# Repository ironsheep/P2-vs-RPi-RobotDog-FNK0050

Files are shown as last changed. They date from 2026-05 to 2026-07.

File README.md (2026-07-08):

# P2-vs-RPi-RobotDog-FNK0050






One of the things I really enjoy doing is finding robotic platforms with a collection of servos and actuators and sensors that look like they'd be fun to control and might be a good challenge for me to expand my skills in programming the P2. When I find these platforms, I look at how they're set up and how compatible they might be. In this case, this was driven by a Raspberry Pi, so I know the interface is going to be pretty easy to adopt when it comes to taking out the Raspberry Pi and replacing it with a P2.

This project is exactly that: the record of me doing this work of replacing a Pi with a P2 and then building the code around it. I built this so you can follow along and play and even use the code if you wish for experiments on your own. 

-*Stephen*

<p align="center">
  Freenove FNK0050 Robot Dog with the Parallax P2 Edge Module mounted where the Raspberry Pi used to sit
</p>

> *The FNK0050 Robot Dog with the Parallax **P2 Edge Module** mounted in place of the Raspberry Pi — the "P2 EDGE" module and chip are visible on top.*

Porting the **Freenove Robot Dog Kit (FNK0050)** from its stock **Raspberry Pi**
controller to a **Parallax Propeller 2 (P2)**. The P2 — on an Edge Module +
breakout board carried by a custom adapter plate — drops into the spot where the
Pi normally sits and mates to the connection board's 40-pin header.

The goal: drive the same robot hardware (13 servos, IMU, battery ADC, ultrasonic
sensor, buzzer, and WS2812 LEDs) from P2 firmware instead of the Pi's Python stack.

> **This build uses connection board PCB v1.0** — so the WS2812 LED data line is on
> **GPIO18** (the `rpi_ws281x` path), not the SPI0/GPIO10 path used by PCB v2.0.

## Why the P2?

The Freenove design puts almost everything on **I²C** behind driver chips
(PCA9685 servo controller, ADS7830 battery ADC, MPU6050 IMU), so most of the port
is "implement an I²C master on the P2." Only three peripherals use discrete GPIO —
the buzzer, the HC-SR04 ultrasonic sensor, and the WS2812 LED strip — and each maps
naturally onto a P2 smart pin. See the wiring map for the full breakdown.

## Repository layout

| Path | Contents |
|---|---|
| [`DOCs/`](DOCs/) | Project documentation — pin usage, the P2 migration wiring map, mounting hardware CAD, and supporting images/sources. |
| `src/` | P2 firmware (Spin2 / PASM2) — work in progress. |
| `REF/` | Upstream Freenove FNK0050 Raspberry Pi code, kept locally for porting reference. **Git-ignored** — not part of this repo's deliverables. |

## Documentation

Start here when planning or executing the hardware swap:

- **[`DOCs/P2-platform/`](DOCs/P2-platform/)** — the **physical-platform hub**: the
  [build walk-through](DOCs/P2-platform/HARDWARE_SETUP.md) (model/print the adapter plate,
  assemble the P2 board onto it, mount it on the robot), the
  [wiring map](DOCs/P2-platform/P2_MIGRATION_WIRING.md) (power architecture, the 3.3 V
  provenance gotcha, the header→P2 map, and the 3.3 V-vs-5 V hazards — the P2 is **not**
  5 V tolerant), and the adapter-plate **CAD** (DXF + 3MF).
- **[`DOCs/RPI_GPIO_USAGE.md`](DOCs/RPI_GPIO_USAGE.md)** — the stock Pi pin/bus
  usage, reverse-engineered from the Freenove server source (no schematic exists).
  Device inventory, I²C addresses, servo channel map, and which signals ride raw GPIO.

## Hardware reference

- **Kit:** Freenove Robot Dog Kit for Raspberry Pi (FNK0050) —
  https://docs.freenove.com/projects/fnk0050/en/latest/
- **Controller (new):** Parallax Propeller 2 Edge Module + breakout board.
- **Power:** 2× 18650 Li-ion (2S), externally charged; the connection board's
  regulator delivers 5 V to the controller. See the wiring map for details.

## Status

Early-stage. Documentation and mechanical/electrical planning are in place; the P2
firmware in `src/` is under development.

## Possible future directions

These are **candidate** directions for after the current port is fully bench-certified — the
**remaining** items are not committed or in progress, and the current firmware does not depend on any
of them. Each is an *input* that posts into the existing cog-0 command mailboxes, so the motion engine
needs no change. **Full detail — hardware candidates, interfaces, and P2-integration notes — is in
[`DOCs/FUTURE-DIRECTIONS.md`](DOCs/FUTURE-DIRECTIONS.md).**

- **Speech recognition** *(✅ implemented in build 0.3.0)* — spoken commands ("sit", "shake", …) via a
  DFRobot DF2301Q offline recognizer on a 2nd I²C bus, feeding the cog-0 command mailboxes. The dog is
  named **Peabody** (wake phrase "Hello Peabody"); see the release notes and
  [`DOCs/subsystems/VoiceSensor/`](DOCs/subsystems/VoiceSensor/).
- **Pan/tilt head + vision AI camera** *(longer-term)* — replace the tilt-only head with a pan/tilt
  mount + an I²C AI camera that reports what it sees (follow / look-at / find).
- **P2 native audio output** *(longer-term)* — real barks / speech via the P2's smart-pin DAC/PWM,
  beyond today's buzzer.
- **Bluetooth remote commanding** *(longer-term)* — a wireless link (SPI / I²C) driving the same
  mailbox command set; the first real "comms cog 0".

---

## License

MIT License - See [LICENSE](LICENSE) for details. © 2026 Iron Sheep Productions, LLC.

Note: the upstream Freenove reference material under `REF/` (git-ignored) is released
by Freenove under CC BY-NC-SA 3.0 and is not covered by this repository's license.

---

*Part of the Iron Sheep Productions Propeller 2 Projects Collection*

---

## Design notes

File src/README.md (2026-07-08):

# `src/` — P2 Firmware Architecture

P2 (Parallax Propeller 2) firmware that replaces the Raspberry Pi controller in the
**Freenove Robot Dog Kit (FNK0050)**. The P2 must drive the same connection-board
hardware the Pi's Python stack drove. Language is **Spin2 / PASM2**, compiled with
**PNut-ts**.

> **Authoritative hardware facts live in `../DOCs/`**, not here. This README is the
> *static* software map — objects, tiers, files, pins. For how the firmware *runs* at
> runtime (cogs, cooperative tasks, the frontend↔backend mailbox protocol), see the
> companion **`../DOCs/P2_FIRMWARE_THEORY_OF_OPS.md`**. For pin/rail facts and their
> confidence levels, see `../DOCs/P2-platform/P2_MIGRATION_WIRING.md` (the swap) and
> `../DOCs/RPI_GPIO_USAGE.md` (the stock Pi usage). Where this README repeats a pin, it is
> for orientation — the wiring doc wins.
>
> **This build targets connection board PCB v1.0** (WS2812 LED data on the discrete data
> line, not the v2.0 SPI path).

---

## 1. Layered object model

Drivers and behaviors stack in **four tiers**. Tiers 1–3 are the per-device driver shape
already established by the seed `isp_i2c_pca9685*` objects;
Tier 4 is the behavioral/coordination layer that composes devices into a robot.

| Tier | Role | Speaks in… | Examples |
|---|---|---|---|
| **1 — transport** | Raw hardware access; one bus / one signal. Knows no device. | bytes, ACK/NAK, pin transitions | `isp_i2c_singleton`, `isp_ws2812.streamBuffer()` |
| **2 — chip** | Register-level access to one device. | register addresses, raw counts | `isp_i2c_pca9685`, `isp_i2c_ads7830` |
| **3 — semantics** | The *user's* mental model of one part. | degrees, volts, named colors | `isp_i2c_pca9685_servo`, `isp_battery_monitor`, `isp_leg`, `isp_head`, `isp_led_ring` |
| **4 — coordination** | Composes many parts into whole-robot behavior. | gaits, poses, commands | `isp_dog_motion`, `isp_io_controller`, `isp_led_engine` |

Three structural notes:

- **The tier boundary is about *vocabulary*, not `PUB`/`PRI`.** Plenty of Tier-2 register
  pokes are `PUB` on purpose (handy for bring-up/probing). What makes a method "Tier-3" is
  that it talks degrees/volts/colors, never register counts.
- **Tiers can split across files *or* live in one file.** I²C devices get a Tier-1 bus
  singleton shared by all chips, so their tiers are separate objects. The WS2812 has no
  shared bus, so its transport+framing live inside one object — like the serial singleton
  keeps its bit-level smart-pin code and its `dec`/`hex`/`fstr` API in one file.
- **Tiers are a static call hierarchy; cogs are a separate runtime partition.** Which cog
  runs which tier — and why all the I²C-bound objects must run in *one* cog — is the
  Theory of Operations' job, not this map's.

---

## 2. Object inventory & dependency tree

```
robot_dog_top        (T4 top: cog0 voice dispatch loop; cogspins the two service cogs)
  ├─ isp_io_controller       (cog1: discrete-pin + voice-bus owner, mailbox B)  → expanded below
  ├─ isp_dog_motion          (cog2: I²C bus-1 owner, mailbox A)                  → expanded below
  ├─ isp_voice_command_names (maps DF2301Q CMDID → phrase text for the dispatch log)
  └─ isp_version             (firmware version constants — single source of truth)

isp_dog_motion            (T4: 4 legs + head + IMU + battery; smooth-motion engine, gait catalog, poses, gestures, leveling)
  ├─ isp_leg  ×4         (T3: one leg; moveToXYZ via shared IK, side-mirror, per-leg calibration)
  │   └─ isp_i2c_pca9685_servo  ×3   (T3 servo, seed)
  ├─ isp_head            (T3: pan/center/sweep, PCA9685 ch 15)
  │   └─ isp_i2c_pca9685_servo
  ├─ isp_imu             (T3: attitude — accel g / gyro °/s)        ─┐
  │   └─ isp_i2c_mpu6050 (T2: MPU6050 registers)                    │
  ├─ isp_battery_monitor (T3: pack volts, low-batt cutoff, median)  │
  │   └─ isp_i2c_ads7830 (T2: ADS7830 counts / pin millivolts)      ├─ isp_i2c_pca9685 (T2)
  └─ isp_calibration     (per-joint servo trims + stance leveling)  │     │
                                                                    │     └─ isp_i2c_singleton (T1: I²C master, bus 1)
isp_io_controller        (T4 IO cog: non-blocking LED + buzzer + ranging + voice service loop)
  ├─ isp_led_engine      (T4: SOLE owner of the ring; sustained base modes + single-shot cues)
  │   └─ isp_led_ring    (T3: display modes; owns LED count)
  │       └─ isp_ws2812  (T1+T2: WS2812 transport + pixel buffer)
  ├─ isp_buzzer          (T2+T3: buzzer, smart pin — no I²C)
  ├─ isp_hcsr04          (T2+T3: ultrasonic, smart pin — no I²C)
  └─ isp_voice_recognizer (T3: DF2301Q @ 0x64 on I²C bus 2, P18/P16; clock-stretch)
      └─ isp_i2c         (T1: VAR/instance I²C master, bus 2)

(every object) ── DEBUG() built-in (debug output over the 2 Mbaud programming UART)
```

All objects below **compile clean** with PNut-ts v1.55 (`pnut-ts -q`). Items marked
**⚠ verify** contain math/timing inferred from the Freenove code or datasheets that must be
validated on hardware (outputs are clamped, so they are safe to run during bring-up).

| File | Tier | Device / role | Notes |
|---|---|---|---|
| `isp_i2c_singleton.spin2` | 1 | I²C bus master | **seed**; shared by all I²C chips. `setup/present/write/read/wr_block/rd_block/stop`. ACK=0, NAK=1 |
| `isp_i2c_pca9685.spin2` | 2 | PCA9685 @ `0x40` | **seed**; 16-ch PWM register driver |
| `isp_i2c_pca9685_servo.spin2` | 3 | servo | **seed**; degrees/µSec, limits, slew ramp tables |
| `isp_i2c_ads7830.spin2` | 2 | ADS7830 @ `0x48` | `readChannelRaw` / `readChannelMillivolts` (divider-agnostic). VREF 5.0 V (consistent with the metered ÷3 battery) |
| `isp_battery_monitor.spin2` | 3 | battery | 9-sample median, **÷3 divider** undo (METERED 2026-06-01), `isLowBattery` (<6.4 V) |
| `isp_ws2812.spin2` | 1·2 | WS2812 strip (7 px) | inline-PASM, CT-paced fixed-cell + GRB buffer (dumb strip). Timing per jm_rgbx_pixel; confirm WS2812 vs B variant |
| `isp_led_ring.spin2` | 3 | LED display modes | off/solid/wipe/chase/rainbow/rainbow-cycle/**rainbow-breathe**; `update()` steps one frame |
| `isp_led_engine.spin2` | 4 | LED engine (sole ring owner) | command-driven: sustained **base** modes + single-shot **cue** overlays (`blink`, latest-wins, revert to base); per-mode pacing (30 ms smooth / 130 ms marching); `service()` stepped by the IO cog. Fixed the earlier multi-writer race |
| `isp_io_controller.spin2` | 4 | discrete-pin + voice-bus IO cog | non-blocking service loop: LED engine + smart-pin ranging + auto-off buzzer + **DF2301Q voice poll (bus 2)**; mailbox B (`postCommand`, `getDistanceMm`/`getPingSeq`/`isLedBusy`, `getVoiceCmdId`/`getVoiceSeq`/`voicePresent`); `start` (voice-off) / `startWithVoice` |
| `isp_i2c_mpu6050.spin2` | 2 | MPU6050 @ `0x68` | wake + ±2g/±250°/s; burst-read accel/gyro raw |
| `isp_imu.spin2` | 3 | attitude | accel milli-g, gyro milli-°/s, `calibrateGyro` (settle + paced + motion-reject → SUCCESS/E_NOT_STILL), `tiltDegrees` (CORDIC). Mahony fusion = TODO |
| `isp_hcsr04.spin2` | 2·3 | HC-SR04 ultrasonic | polled `readDistanceMm`/`Cm` **and** non-blocking smart-pin path (`startSmart`/`firePing`/`echoReadyMm`) ⚠ verify integrated |
| `isp_buzzer.spin2` | 2·3 | buzzer | active buzzer `on`/`off`/`beep` (IO cog drives non-blocking via auto-off tick) |
| `isp_leg.spin2` | 3 | one leg (3 servos) | `init(side, ending)`, `setJointAngles`, `moveToXYZ` (CORDIC IK ⚠ verify) |
| `isp_head.spin2` | 3 | head pan (ch 15) | `panTo`/`center`/`sweep` |
| `isp_calibration.spin2` | 3 | per-robot trims | per-joint servo trims (metered) + head trim + **static stance leveling** (`stanceTrimY`) |
| `isp_dog_motion.spin2` | 4 | body coordinator | `{Spin2_v47}` cooperative tasks; mailbox A; smooth-motion engine (50 Hz eased), full gait catalog + speed knob, stand/relax/sit, hello, leveling ⚠ verify |
| `isp_i2c.spin2` | 1 | I²C bus master (VAR/instance) | clock-stretch-honoring instance variant for **bus 2** (voice); mirrors the DAT singleton but stores bus state per-instance |
| `isp_voice_recognizer.spin2` | 3 | DF2301Q @ `0x64` (bus 2) | offline voice recognizer over `isp_i2c`; `getCMDID`/`pollCMDID`, `playByCMDID`, `setVolume`/`setWakeTime`, register-liveness presence probe (defeats parasitic-power false positive) |
| `isp_voice_command_names.spin2` | 3 | CMDID → phrase names | built-in vocabulary tables + `registerCustomTable()` for custom slots 5–21; `cmdName(id)` → text (dispatch log) |
| `isp_version.spin2` | — | firmware version | single source of truth `FW_VERSION_MAJOR/_MINOR/_PATCH` (0.3.0) |
| `robot_dog_top.spin2` | 4 | integrated 3-cog top | `cogspin`s IO (cog1) + backend (cog2); runs the **persistent voice dispatch loop** — maps recognized CMDID→`CMD_*` (`voiceToDogCmd()`) and posts to mailbox A through the motion gate; legacy scripted self-test behind `DEMO_ON_BOOT` ⚠ verify (live voice→motion) |

There is **no shared OBEX driver** for the ADS7830, MPU6050, or HC-SR04 — each is
hand-rolled on the seed I²C singleton (or a smart pin). The **full gait catalog**
(forward/backward, turn L/R, sidestep L/R) and the hello gesture in `isp_dog_motion` are
implemented on the smooth-motion engine (build 0.1.1); on-bench behavioral verification is
pending (the trajectory math is still ⚠ verify).

---

## 3. The leg model (Tier 3 → Tier 4)

The 12 leg-joint PCA9685 channels group into **4 legs of 3 joints** (coxa *a* / femur *b* /
tibia *c*; link lengths l1=23, l2=55, l3=55 mm). A leg is created with its body position —
**`init(side, end)`** — and derives its own channel triple, joint-angle mirror, and gait
role from that identity.

| Leg | Side | End | coxa (a) | femur (b) | tibia (c) |
|-----|---|-----|---|---|---|
| FL | Left | Front | ch 4 | ch 3 | ch 2 |
| BL | Left | Back | ch 7 | ch 6 | ch 5 |
| BR | Right | Back | ch 8 | ch 9 | ch 10 |
| FR | Right | Front | ch 11 | ch 12 | ch 13 |

- **Side** owns the joint-angle **mirror**: Left legs apply `[a, 90−b, c]`; Right legs apply
  `[a, 90+b, 180−c]`. (Left channels count *down*; Right count *up* — the physical mirror.)
- **End** owns the **gait phase** and stance-offset sign. Diagonal phase pairs are {FL,BR}
  and {FR,BL}.
- **IK lives in `isp_leg`** (`moveToXYZ` = shared `coordinateToAngle` + side-mirror + this
  leg's calibration → 3 servo writes). The **body coordinator** (`isp_dog_motion`) generates
  per-leg target coordinates for gaits/poses and calls each leg.
- **Motion timing lives at the body level (the smooth-motion engine).** `isp_dog_motion` owns a
  CT-gated 50 Hz frame loop with body-level foot-target arrays (`cur/tgt/start[]`, leg order
  FL/BL/FR/BR), an ease-in/out smoothstep, per-frame reachability guard, and blend-from-current —
  so all 13 joints share one timebase and start/arrive together (no per-servo slew, no snaps). It
  drives the **full gait catalog** (forward/backward, turn L/R, sidestep L/R; trotting diagonals
  with an `arg0` speed knob). All poses and gaits share one neutral — the **loaded-rear crouch** —
  through a single source of truth, `neutralFootTarget(idx)` / `neutralFootY(idx)`: front feet at
  `NEUTRAL_FRONT_Y_MM=95`, rear folded deeper to `NEUTRAL_REAR_Y_MM=85` and tucked back
  (`NEUTRAL_REAR_X_MM=−12`) for a ~60:40 forward bias. Gaits clamp each foot's lift to its **own**
  per-leg planted floor (`plantFloor`), so the front/rear height split survives walking;
  `STAND_HEIGHT_MM=99` is retained only as the *tall* SIT/BOW/PARADE reference. The neutral folds in
  the **IMU static-leveling** stance trim (`isp_calibration.stanceTrimY`). The behavioral contract is
  specified in
  [`../DOCs/spec/P2-RobotDog-Specifications.md`](../DOCs/spec/P2-RobotDog-Specifications.md); the
  as-built engine is ToOps §6.2.
- **The three cogs are assembled in `robot_dog_top`** — it `cogspin`s `isp_io_controller` (cog 1:
  discrete pins + voice bus, mailbox B) and the backend (cog 2: I²C, mailbox A), and runs the
  **persistent voice dispatch loop** on cog 0 (maps a recognized CMDID → `CMD_*` via `voiceToDogCmd()`
  and posts to mailbox A through the motion gate).

> ✅ The FL/BL/BR/FR ↔ channel assignment is **verified on hardware 2026-06-01** — each commanded
> leg moved the matching physical leg (FL=4/3/2, BL=7/6/5, BR=8/9/10, FR=11/12/13, head=15). The
> joint-angle **side mirror** and the **CORDIC IK** still need validation through motion (the
> calibration step). Note: at center the FL/BR toes sit slightly low → small tibia trim pending.

Head is a single DOF (PCA9685 **ch 15**, center ≈ 90°, ~50–130°). `isp_head` is intentionally
thin — it earns its keep as the mount point for the future head-pan + ultrasonic scan.
Whole-robot gestures (push-ups, the "hello" wave — which actually waves a *leg*) belong to
`isp_dog_motion`, not the head.

---

## 4. P2 pin map (as-built P8–P15)

**As-built adapter map, verified on hardware 2026-05-31** (base P8; offsets LED +0, ECHO +1,
Buzzer +2, TRIG +3, SCL +5, SDA +7). **Authoritative table + rationale:
`../DOCs/P2-platform/P2_MIGRATION_WIRING.md` §3.**

| P2 pin | Robo hdr pin | Signal | Driver object | Transport |
|---|---|---|---|---|
| P8 | 12 | WS2812 LED data | `isp_ws2812` | inline PASM2 |
| P9 | 15 | Ultrasonic ECHO (input) | `isp_hcsr04` | smart pin (pulse in); **~1 kΩ inline series R** |
| P10 | 11 | Buzzer | `isp_buzzer` | smart pin |
| P11 | 13 | Ultrasonic TRIG | `isp_hcsr04` | smart pin (pulse out) |
| P12 | — | *spare* | — | — |
| P13 | 5 | I²C SCL | `isp_i2c_singleton` | I²C (`PU_1K5`) |
| P14 | — | *spare* | — | — |
| P15 | 3 | I²C SDA (bus 1) | `isp_i2c_singleton` | I²C (`PU_1K5`; 6.9 kΩ board pull-down) |
| P16 | — | I²C SDA (**bus 2, voice**) | `isp_voice_recognizer` via `isp_i2c` | I²C (`PU_1K5`) |
| P18 | — | I²C SCL (**bus 2, voice**) | `isp_voice_recognizer` via `isp_i2c` | I²C (`PU_1K5`) |

> **Bus 2 (voice)** — P16/P18 sit **outside** the P8–P15 as-built block (they were unallocated). The
> DF2301Q voice recognizer (`0x64`) wires **direct to the module**, not through the robot header, and is
> owned by the IO cog (cog 1). See wiring §3a.

### Devices behind the I²C bus (P13/P15)

| Device | Addr (7-bit) | Driver | Role |
|---|---|---|---|
| PCA9685 | `0x40` | `isp_i2c_pca9685(_servo)` | 13 servos: ch 2–13 = four legs (3 joints each), ch 15 = head pan; 0–180° → count 102–512 |
| ADS7830 | `0x48` | `isp_i2c_ads7830` → `isp_battery_monitor` | battery ADC ch 0; cutoff < 6.4 V |
| MPU6050 | `0x68` | `isp_i2c_mpu6050` → `isp_imu` | 6-axis IMU for balance/attitude |

> All three I²C devices share **one** physical bus → exactly one cog may drive it. See the
> Theory of Operations for the bus-ownership rule.
>
> Drivers store the address **pre-shifted** (e.g. ADS7830 = `$90` = `0x48 << 1`) and OR in
> `MODE_WRITE` (0) / `MODE_READ` (1), matching the PCA9685 convention.

---

## 5. Runtime overview (→ Theory of Operations)

The static tiers above are partitioned across P2 cogs at runtime, by **resource ownership** —
comms plus two service cogs, one per hardware domain. In brief:

- **Cog 0 — comms / voice dispatch:** owns the command link only; runs the persistent voice dispatch
  loop — reads the IO cog's voice telemetry, maps each CMDID → behavior (`voiceToDogCmd()`), and posts
  intents to both service cogs while reading their telemetry. Never blocks on a peripheral.
- **Cog 1 — discrete-pin + voice IO** (launched first): owns the **non-I²C pins** — WS2812 LED (P8),
  buzzer (P10), ultrasonic (ECHO P9 / TRIG P11) — **and I²C bus 2** (P18/P16) for the DF2301Q voice
  recognizer. One owner per pin (cross-cog pin handoff is costly); runs the LED engine, ranging, beeps,
  and voice polling as non-blocking tasks (smart-pin timing → ~1 % cog load, no jitter); it is the
  ultrasonic distance producer and the recognized-CMDID producer.
- **Cog 2 — backend body-control:** the **sole owner of I²C bus 1** (servos + IMU + battery); runs
  motion and IMU/battery sensing as **Spin2 v47 cooperative tasks** — so the shared bus is never
  touched by two cogs, with no lock.

Each service cog is fed by its own hub mailbox (commands in, telemetry out). The full cog map,
the concurrency model, the mailbox protocol, and the backend state machine are documented in
**`../DOCs/P2_FIRMWARE_THEORY_OF_OPS.md`**.

---

## 6. Electrical gotchas (recap — see wiring doc for the authoritative treatment)

- **The P2 cannot *drive* 5 V, and a *bare* pin must stay ≤ ~3.6 V — but it can safely *read* 5 V
  through a series resistor** (the pin's internal clamp diode to VIO absorbs the overshoot at ≤ 10 mA,
  so R ≥ (Vin − 3.6)/10 mA ≈ 1 kΩ). **HC-SR04 ECHO** carries **undivided 5 V** on header pin 15 (the
  board does *not* divide it, metered 2026-05/06-01), so it reaches **P9 through a ~1 kΩ series R** —
  ranging is verified working. **WS2812** data is 3.3 V out into a 5 V strip (works on this hardware; a
  74AHCT125 level shifter is the robust fix if the first pixel is ever flaky).
- **The 3.3 V rail vanishes with the Pi.** The adapter must put 3.3 V back on header
  pins 1/17 for the board's I²C pull-ups/chips. (#1 gotcha.)
- **Power flows robot → controller**: feed the P2 board 5 V (header pins 2/4); it regulates
  3.3 V on-board.
- **Keep I/O on P0–P57.** P58–P61 = boot flash, P62/P63 = serial/programming.

Constants once flagged `INFERRED` are being retired as hardware confirms them: the battery
divider is now **METERED ÷3** (2026-06-01), not the ÷2 traced from Freenove code; WS2812 bit
timing matches `REF jm_rgbx_pixel` (only the strip variant needs confirming); the **leg↔channel
map is verified** (2026-06-01). Still to validate through motion: the joint side-mirror, the CORDIC
IK, and per-joint servo trim (the calibration step).

---

## 7. Building

Compiled with **PNut-ts** (`pnut-ts`, v1.55.0+ in this container).

```bash
# Compile one object as the top file (pulls in its child objects automatically):
pnut-ts -q src/isp_ws2812.spin2          # → isp_ws2812.bin

# Useful flags:
pnut-ts -l src/isp_i2c_ads7830.spin2     # also emit .lst listing
pnut-ts -d src/<top>.spin2               # compile with DEBUG
```

Each driver is written so it compiles standalone (it is a valid top object even though its
`null()` notes "not a top-level object"). Objects using cooperative tasks must begin with
the **`{Spin2_v47}`** version directive.

### Proving drivers on hardware — `test_*.spin2` harnesses

Each interface has a dedicated **auto-run** top file (`test_led`, `test_i2c_scan`, `test_buzzer`,
`test_ping`, `test_battery`, `test_imu`, `test_servo_center`, `test_servo_wiggle`, plus `test_smoke`)
that brings up **one** driver, runs it
for a bounded time, and emits P2 `DEBUG()` (no serial singleton, no menu, no keystrokes). Each
declares `DEBUG_BAUD = 2_000_000`, is compiled with `-d`, and ends with `DEBUG("TEST_DONE")`:

```bash
pnut-ts -d -q src/test_i2c_scan.spin2                                       # build with DEBUG
pnut-term-ts -r src/test_i2c_scan.bin -b 2000000 --headless \
             --end-marker "TEST_DONE" --timeout 12                          # download-to-RAM, run, capture
```

> **`-b 2000000` is required.** In `--headless` mode `pnut-term-ts` opens the port at 115200 for the
> *download* (fine, ignore it) but does **not** auto-apply the debug baud to the *runtime* read — so
> 2 Mbaud `DEBUG` comes back as garbage unless you pass `-b 2000000`. Logs land in `logs/`.

These were used for the 2026-06-01 bring-up (results: `../DOCs/P2-platform/P2_MIGRATION_WIRING.md` §7). The smooth-motion bench tests
**all run the production 3-cog shape** (both service cogs launched, isolation by what cog 0
commands — never a single-cog shape): **`test_dog_stand.spin2`** (eased poses), **`test_dog_level.spin2`**
(IMU static-leveling measure), and **`test_dog_gaits.spin2`** (full gait catalog + speed) each keep
the IO cog present-but-quiescent (static LED, ranging dormant), while **`robot_dog_top.spin2`**
runs the **persistent voice dispatch loop** by default (the legacy full-concurrency self-test — LED
animation + live ranging + motion + beep at once — is preserved behind `DEMO_ON_BOOT`). They drive
`DOCs/plans/SMOOTH-MOTION-AND-INTEGRATION-TEST-PLAYBOOK.md`. Voice is exercised in isolation by
**`test_voice.spin2`** (do we hear commands over I²C bus 2) and **`test_voice_map.spin2`** (catalog the
trained custom slots 1:1); the LED engine by **`test_led_engine.spin2`** / **`test_led_onoff.spin2`**.
The real frontend comms cog (Wi-Fi/serial command link) is still **TODO** — **voice is today's command
source**.

`.bin` / `.lst` / `.obj` outputs are build artifacts — don't commit them.

---

## 8. Conventions

- **Coding standards (authoritative):** every `.spin2` file MUST follow
  [`../DOCs/policy/SPIN2-AUTHORING-GUIDE.md`](../DOCs/policy/SPIN2-AUTHORING-GUIDE.md) —
  ASCII-only, VSCode/PNUT_TS doc-comment style (`@param`/`@returns`/`@local`), single exit
  point, `quit` (never `return`) from loops, named constants (no magic numbers), descriptive
  names (no single-letter/generic locals), and object constants referenced via the OBJ
  prefix. The guide's checklist is the pre-commit gate.
- **Naming:** `isp_<...>.spin2`, Iron Sheep Productions prefix. If the device is reached over
  **I²C**, put `i2c` in the name (`isp_i2c_ads7830`); smart-pin / single-signal / behavioral
  objects omit it (`isp_ws2812`, `isp_hcsr04`, `isp_leg`, `isp_dog_motion`).
- **Debug:** objects emit diagnostics via the built-in `DEBUG()` (compiled out unless the
  debugger is attached); output lands on the 2 Mbaud programming UART.
- **License:** MIT, © Iron Sheep Productions, LLC (see each file's footer). Upstream
  Freenove `REF/` material is CC BY-NC-SA 3.0 and is **excluded** from this repo.
- **P2 KB / OBEX:** for PASM2/Spin2 questions and reusable objects, use the **p2kb-mcp**
  tools (authoritative) rather than web search.

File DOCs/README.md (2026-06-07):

# DOCs — P2 Robot Dog documentation hub







Documentation for porting the **Freenove Robot Dog Kit (FNK0050)** from its stock Raspberry
Pi controller to a **Parallax Propeller 2**. Start at the top-level [project README](../README.md);
this page indexes everything under `DOCs/` and records how we reference the upstream Freenove
material.

## Top-level documents

| Document | What it is |
|---|---|
| [`RPI_GPIO_USAGE.md`](RPI_GPIO_USAGE.md) | The stock Pi pin/bus usage, reverse-engineered from the Freenove server source — device inventory, I²C addresses, servo channel map. |
| [`P2_FIRMWARE_THEORY_OF_OPS.md`](P2_FIRMWARE_THEORY_OF_OPS.md) | Theory of operation for the P2 firmware — the cog architecture and the basic→advanced motion progression. |
| [`DOG-LIKE-MOTION-STUDY.md`](DOG-LIKE-MOTION-STUDY.md) | Canine-biomechanics findings + the prioritized plan to make the gaits and poses more dog-like. |
| [`FUTURE-DIRECTIONS.md`](FUTURE-DIRECTIONS.md) | Candidate post-certification directions — speech, vision/pan-tilt head, P2 audio, BLE, active IMU balance. |
| [`pin-header.pdf`](pin-header.pdf) | The 40-pin connection-board header pin-out diagram (source in [`sources/`](sources/)). |

## Subfolders

| Folder | Contents |
|---|---|
| [`P2-platform/`](P2-platform/) | The physical swap — build walk-through, the migration wiring map, and the adapter-plate CAD. |
| [`spec/`](spec/) | The authoritative firmware specification. |
| [`policy/`](policy/) | Authoring conventions (the Spin2 guide). |
| [`plans/`](plans/) | Active sprint plan, bench playbook, and punch list (closed plans in `plans/archive/`). |
| [`dbg-display-theory/`](dbg-display-theory/) | How we build the P2 DEBUG-window display panels. |
| [`reference/`](reference/) | User guides for reused helper objects. |
| [`datasheet/`](datasheet/) | Vendor datasheets for the on-board parts (third-party). |
| [`Picture/`](Picture/) | Images referenced by the docs. |
| [`sources/`](sources/) | Editable diagram source files. |

## Upstream / external reference material — Freenove FNK0050

This port is built against Freenove's open-source kit. We reference that material in two
places, and **neither is covered by this project's MIT license**:

- **The Freenove Raspberry Pi Python stack** lives locally in `REF/` as **read-only**
  porting reference. It is **git-ignored** — never committed to this repo — and is the source
  the P2 drivers were reverse-engineered from (see [`RPI_GPIO_USAGE.md`](RPI_GPIO_USAGE.md)).
- **Kit photos** under [`Picture/`](Picture/) (the kit icon and the PCB-version photos) come
  from Freenove.

Freenove's materials are released under the
[Creative Commons Attribution-NonCommercial-ShareAlike 3.0 license](http://creativecommons.org/licenses/by-nc-sa/3.0/),
and the Freenove brand and logo are their property. Their upstream repository:
[Freenove_Robot_Dog_Kit_for_Raspberry_Pi](https://github.com/Freenove/Freenove_Robot_Dog_Kit_for_Raspberry_Pi).

> **This build targets connection-board PCB v1.0** (WS2812 LED data on GPIO18 — the
> `rpi_ws281x` path, not the v2.0 SPI0/GPIO10 path).

<table>
  <tr><th>PCB Version</th><th>Photo</th></tr>
  <tr>
    <td align="center"><b>V1.0</b> <em>(this build)</em></td>
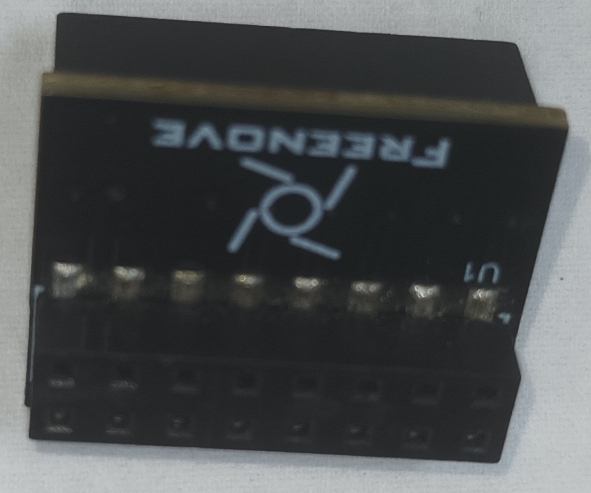
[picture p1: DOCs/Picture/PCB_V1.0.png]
Connection board V1.0
    <td align="center"></td>
  </tr>
  <tr>
    <td align="center">V2.0</td>
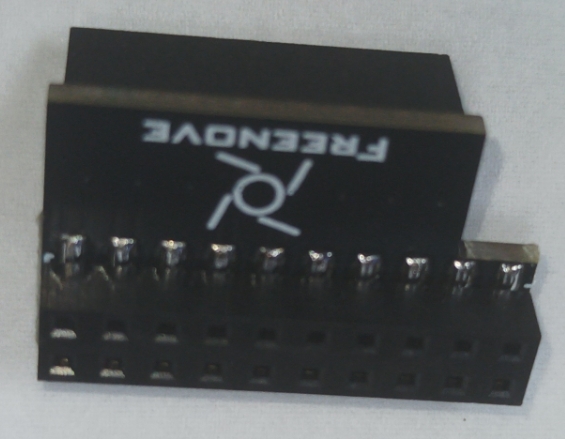
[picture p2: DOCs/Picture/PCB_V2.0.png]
Connection board V2.0
    <td align="center"></td>
  </tr>
</table>

---

## License

The documentation in this `DOCs/` tree is authored by Iron Sheep Productions, LLC and
released under the MIT License — See [LICENSE](../LICENSE) for details. **Exceptions:** the
Freenove-sourced kit images and the third-party vendor datasheets noted above retain their
respective owners' licensing and are **not** covered by MIT.

---

*Part of the Iron Sheep Productions Propeller 2 Projects Collection*

---

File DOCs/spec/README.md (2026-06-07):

# spec — firmware specifications






The authoritative firmware specification for the P2 Robot Dog — the contract the code is
written to. The companion narrative is [`../P2_FIRMWARE_THEORY_OF_OPS.md`](../P2_FIRMWARE_THEORY_OF_OPS.md).

| File | What it covers |
|---|---|
| [`P2-RobotDog-Specifications.md`](P2-RobotDog-Specifications.md) | Full firmware spec — overview, the smooth-motion engine contract, the verified neutral stance, the gait catalog, IMU leveling, and the leg kinematics / servo facts / per-joint clamps / calibration (§8). |

---

## License

MIT License - See [LICENSE](../../LICENSE) for details.

---

*Part of the Iron Sheep Productions Propeller 2 Projects Collection*

---

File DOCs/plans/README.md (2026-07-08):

# plans — sprint plans, playbooks & the punch list






Working planning documents — the **active** sprint plan, the bench-verification playbook
it executes against, and the running punch list. Completed/superseded plans move to
[`archive/`](archive/) so this level always shows what's live.

### Active

| File | What it is |
|---|---|
| [`PUNCH-LIST.md`](PUNCH-LIST.md) | Running list of small open/deferred items (e.g. LED gamma correction). |
| [`VOICE-INTEGRATION-SPRINT-PLAN.md`](VOICE-INTEGRATION-SPRINT-PLAN.md) | The voice-recognition sprint plan. |
| [`VOICE-INTEGRATION-TEST-PLAYBOOK.md`](VOICE-INTEGRATION-TEST-PLAYBOOK.md) | Its bench-verification playbook. |

_The **Voice Integration** sprint shipped in build 0.3.0 (2026-06-11): the 2nd-bus voice recognizer, the
cog-0 dispatch loop, the confirmed **17-word command map** (`voiceToDogCmd()` wired live, plus built-in
aliases), and the command-driven **LED engine** are all **code-complete and bench-confirmed**. Remaining
before closeout/archive: the **live end-to-end voice→motion demo** and the **full LED feedback scheme**.
(The earlier **Dog-Like-Motion-01 Keystone** sprint closed at build 0.2.0 and is in [`archive/`](archive/).)_

> Note: the voice sprint plan/playbook were authored for the **plumbing** phase, when the map seam
> deliberately returned `CMD_NONE`. The CMDID→behavior map has **since been completed** — see
> [`../subsystems/VoiceSensor/VOICE-COMMAND-MAP.md`](../subsystems/VoiceSensor/VOICE-COMMAND-MAP.md) and
> the Theory of Operations §2/§5 for the current behavior.

### Archive

Closed-out plans, kept for history — see [`archive/`](archive/).

---

## License

MIT License - See [LICENSE](../../LICENSE) for details.

---

*Part of the Iron Sheep Productions Propeller 2 Projects Collection*

---

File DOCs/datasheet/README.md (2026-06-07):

# datasheet — vendor datasheets for the on-board parts






Manufacturer datasheets for the silicon on the Robot Dog connection board, kept locally
so the register-level details are at hand while writing the P2 drivers. Device roles and
I²C addresses are summarized in [`../RPI_GPIO_USAGE.md`](../RPI_GPIO_USAGE.md) and the
top-level [`CLAUDE.md`](../../CLAUDE.md).

| File | Part | Role in this build |
|---|---|---|
| [`PCA9685.pdf`](PCA9685.pdf) | NXP PCA9685 | 16-channel PWM @ 50 Hz, I²C `0x40` — drives the 13 servos (12 leg joints + head). |
| [`ADS7830.pdf`](ADS7830.pdf) | TI ADS7830 | 8-channel 8-bit ADC, I²C `0x48` — battery voltage on ch 0 (÷3 divider). |
| [`mpu-6050_datasheet_v3 4.pdf`](mpu-6050_datasheet_v3%204.pdf) | InvenSense MPU-6050 | 6-axis IMU, I²C `0x68` — balance / attitude. |
| [`WS2812.pdf`](WS2812.pdf) | WorldSemi WS2812 | Addressable RGB LEDs (7-px ring) on GPIO18 / P8. |
| [`28029-Smart-Sensors-Text-v1.0.pdf`](28029-Smart-Sensors-Text-v1.0.pdf) | Parallax #28029 | Smart-Sensors text — ultrasonic ranging (HC-SR04-style TRIG/ECHO) background. |

> These PDFs are **third-party manufacturer documents**, redistributed here only as a
> convenience for development. Each remains the copyright of its respective vendor and is
> **not** covered by this project's MIT license.

---

## License

MIT License - See [LICENSE](../../LICENSE) for details.

---

*Part of the Iron Sheep Productions Propeller 2 Projects Collection*

---

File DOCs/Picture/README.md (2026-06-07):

# Picture — images for the docs






Images referenced by the project [`README`](../../README.md), the [`DOCs` hub](../README.md),
and the [`HARDWARE_SETUP`](../P2-platform/HARDWARE_SETUP.md) build guide. The kit icon and
PCB-version photos are Freenove-sourced (see the [`DOCs` hub](../README.md#upstream--external-reference-material--freenove-fnk0050)).

### Kit / board reference

| File | What it is |
|---|---|
| `icon.png` | Robot Dog kit icon / hero image. |
| `PCB_V1.0.png` | Photo of the **v1.0** connection board (this build's PCB — WS2812 data on GPIO18). |
| `PCB_V2.0.png` | Photo of the **v2.0** connection board (LED data on the SPI0/GPIO10 path). |

### Build photos (see [`HARDWARE_SETUP.md`](../P2-platform/HARDWARE_SETUP.md))

| File | Phase | What it is |
|---|---|---|
| `p2-platform.png` | Model | CAD model of the P2 adapter/mount plate. |
| `test-3d-prints.png` | Model | Three 3D-printed test plates from standoff/hole-alignment tuning. |
| `parts-for-assembly.png` | Assemble | P2 Edge Module, breakout board, plate, fasteners, tools laid out. |
| `brd-mounted.png` | Assemble | Breakout board fastened to the plate's standoffs. |
| `edge-mounted.png` | Assemble | P2 Edge Module seated in the breakout board (top). |
| `edge-mounted-underside.png` | Assemble | Underside — hex nuts securing the board to the plate. |
| `dog-rdy-for-p2.png` | Mount | Robot with the Pi removed, connection board exposed and ready. |
| `camera-ribbon-taped.png` | Mount | Camera ribbon cable taped/insulated during the swap. |
| `fullbody-left.png` | Mount | Completed build — left angled view (PropPlug/power-header side). |
| `fullbody-right.png` | Mount | Completed build — right angled view (P2 Edge Module side). |

Not used in the docs (angled views above were preferred): `fullbody-straight-left.png`,
`fullbody-straight-right.png`.

---

## License

MIT License - See [LICENSE](../../LICENSE) for details.

---

*Part of the Iron Sheep Productions Propeller 2 Projects Collection*

---

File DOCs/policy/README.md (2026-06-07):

# policy — authoring conventions for this codebase






Conventions and rules to follow when writing code for this project. These exist to keep the
firmware consistent and to head off the language traps that cost real bench time.

| File | What it covers |
|---|---|
| [`SPIN2-AUTHORING-GUIDE.md`](SPIN2-AUTHORING-GUIDE.md) | Spin2 language rules and house conventions — ASCII-only, the `>=` vs `=>` operator trap, case-insensitive name collisions, no method overloading, and more. |

---

## License

MIT License - See [LICENSE](../../LICENSE) for details.

---

*Part of the Iron Sheep Productions Propeller 2 Projects Collection*

---

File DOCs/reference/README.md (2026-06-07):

# reference — user guides for reused objects






Reference material — user guides for the helper objects this firmware reuses, so their API
and usage are documented in one place.

| File | What it covers |
|---|---|
| [`isp_stack_check_UserGuide.md`](isp_stack_check_UserGuide.md) | `isp_stack_check` — the cog stack-usage probe: why you need it, quick start, and the public API (constants + methods). |

---

## License

MIT License - See [LICENSE](../../LICENSE) for details.

---

*Part of the Iron Sheep Productions Propeller 2 Projects Collection*

---

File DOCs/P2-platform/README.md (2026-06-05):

# P2-platform — the physical platform (build + wiring + CAD)






Everything about the **physical swap** — dropping a **Propeller 2 Edge Module + breakout
board** into the spot where the Raspberry Pi normally sits on the Robot Dog connection
board. This folder holds the build walk-through, the electrical wiring map, and the
adapter-plate CAD:

- **[`HARDWARE_SETUP.md`](HARDWARE_SETUP.md)** — photo walk-through: model + print the
  adapter plate, assemble the P2 board onto it, mount it on the robot.
- **[`P2_MIGRATION_WIRING.md`](P2_MIGRATION_WIRING.md)** — the electrical side of the swap:
  power architecture, the 3.3 V provenance gotcha, the header→P2 wiring map, and the
  3.3 V-vs-5 V level-shifting hazards (the P2 is **not** 5 V tolerant).
- **Adapter-plate CAD** — the editable plate models (see *Files* below).

The rest of this README is the **CAD story** — how the adapter plate was modeled and printed.

## The model

The plate is modeled in Shapr3D to match the Pi's mounting footprint, with raised standoff
bosses positioned to carry the P2 Edge breakout board:

<p align="center">
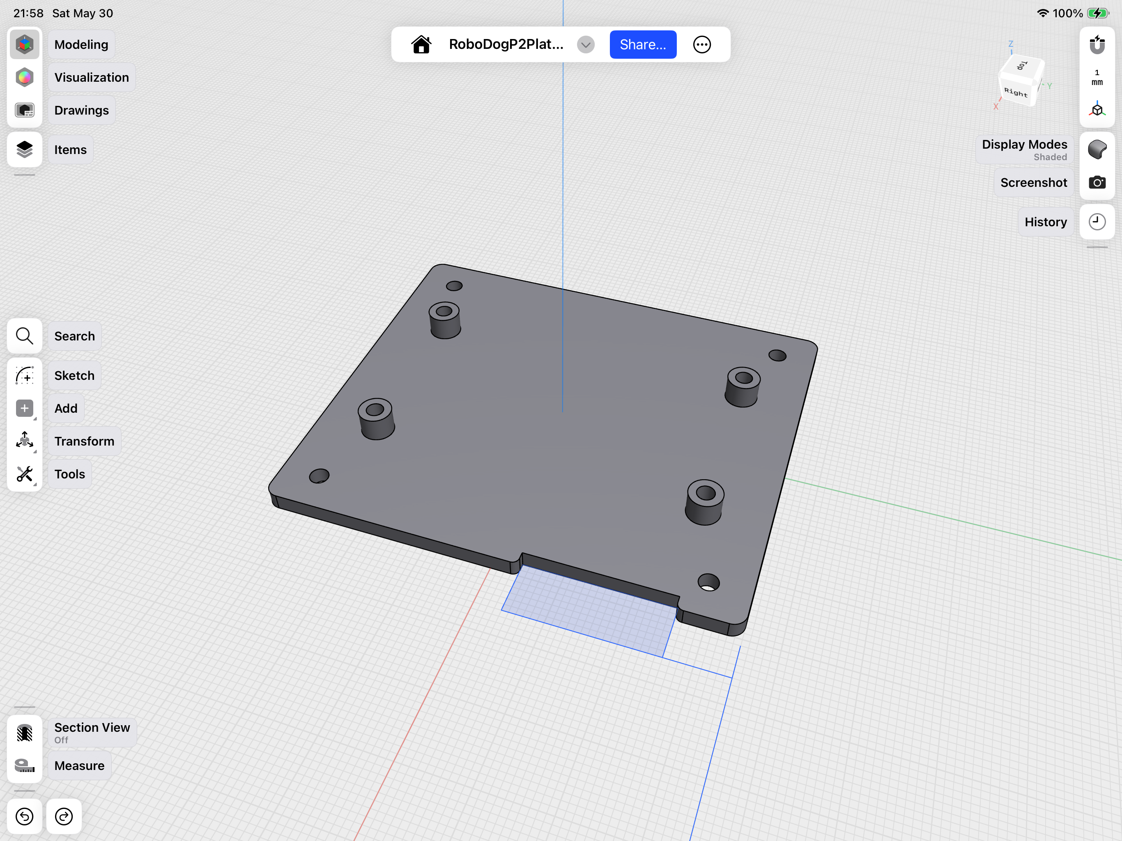
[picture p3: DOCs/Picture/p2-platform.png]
Shapr3D CAD model of the P2 mount plate
  
</p>

## How I developed the model

So I'm a heavy Claude Code user, and I decided to try an experiment. The geometry and pin mounting points for the P2 Edge modules are well-known and publicly documented, as are the Raspberry Pi mounting holes. I asked Perplexity, in this case, to study and gather the mounting information (mounting hole sizes and locations), and then to overlay the two with the same orientation. I described how I wanted the platform to look, and then I had Perplexity give me the constraints for drawing it. Perplexity can't produce files, so it gave me the specification for the model file that I'd want. I copied that specification into Claude Code, and I said, "OK, now write the 2D design file that Shapr3D can read." It did that beautifully, and in fact, it did it in one pass. The first one was correct. I was able to use it.

The next thing I did was import the file into Shapr3D and apply the standard extrusion techniques to create a 3D model. I printed some lightweight tests so I could prove that all the geometry was correct, and pleasantly so, the geometry was perfectly correct. I never had to move a hole placement. The only thing that might have been better is if the inner diameter of the standoffs had been narrower, so the screw could have threaded itself. As a result of not paying attention to that, I had to use nuts to hold the screws in place for the P2 Edge standoffs.  

The final thing is, you'll see the very first print I produced was perfectly rectangular. When I laid it down, I realized that the pins on the board underneath, where I would have to connect that header to the P2, were too close to this board. The last thing I had to do then was create an inset so the header would have more clearance around it, allowing me to plug in the cables. That was the final modification, which is why the first one in the following print regression is rectangular, while the second and third have the inset.  Anyway, I thought this would be interesting for you to know. -Stephen

## Print progression

Getting the standoff height and hole alignment right took a few iterations. The trick is to
print **thin, quick test plates first** — just enough plate to verify the mounting-hole
positions and the board footprint line up — before committing the time and filament to the
full-height (taller-standoff) plate. Here are three of those test plates, ending in the V2
design:

<p align="center">
  Three 3D-printed test plates showing the design progression
</p>

## Files

| File | Format | What it is |
|---|---|---|
| `HARDWARE_SETUP.md` | doc | Build walk-through — model/print the plate, assemble the P2 board, mount on the robot. |
| `P2_MIGRATION_WIRING.md` | doc | Electrical swap — power architecture, header→P2 wiring map, 3.3 V-vs-5 V hazards. |
| `pi_p2_mount_plate.dxf` | DXF (2D CAD) | Outline/drilling drawing of the mount plate — Pi-footprint mounting holes mapped to the P2 board. Open in any CAD tool or for laser/CNC. |
| `RoboDogP2PlateV2.3mf` | 3MF (3D model) | Printable V2 mount plate for the P2 platform. Slice and 3D-print. |

---

## License

MIT License - See [LICENSE](../../LICENSE) for details.

---

*Part of the Iron Sheep Productions Propeller 2 Projects Collection*

---

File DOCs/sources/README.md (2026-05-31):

# sources — editable diagram sources






Original, editable source files for diagrams that are exported elsewhere in
`DOCs/`. Keep these so the published artifacts can be regenerated.

| File | App | Exports to |
|---|-----|---|
| `pin-header.graffle` | OmniGraffle | [`../pin-header.pdf`](../pin-header.pdf) — the 40-pin header pin-out diagram. |

---

## License

MIT License - See [LICENSE](../../LICENSE) for details.

---

*Part of the Iron Sheep Productions Propeller 2 Projects Collection*

---

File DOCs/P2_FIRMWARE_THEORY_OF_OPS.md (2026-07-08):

# P2 Firmware — Theory of Operations

How the Robot Dog (FNK0050) P2 firmware *runs*: the cog partition (comms + two
resource-owner service cogs), the cooperative-task concurrency model, and the comms↔service
mailbox protocol. This is the **dynamic**
companion to the **static** structure in [`../src/README.md`](../src/README.md) (objects,
tiers, files, pins). When the two overlap, this document owns runtime behavior; the README
owns the object/tier map.

> Status: **as-built for build 0.3.0; bench verification ongoing.** All Tier 1–4 objects exist in
> `src/` and compile clean (PNut-ts). The three-cog wiring **is assembled** —
> `src/robot_dog_top.spin2` `cogspin`s the IO cog (cog 1, launched first) and the backend (cog 2) and
> runs the **persistent voice dispatch loop** on cog 0 over mailboxes A + B (was a scripted orchestrator;
> the real Wi-Fi/serial command link is still deferred — for now **voice is the command source**). The IO
> cog's **smart-pin ultrasonic + non-blocking buzzer + command-driven LED engine** are built and launched,
> and it now also owns the **2nd I²C bus** carrying the **DF2301Q voice recognizer**, publishing recognized
> CMDIDs as latest-wins telemetry. **The cog-0 dispatch loop now maps each recognized CMDID → behavior** —
> the `voiceToDogCmd()` seam is fully wired (custom slots 5–21 → `CMD_*`, plus built-in aliases 22/23) and
> posts mapped commands to the backend through the motion gate; the 17-word vocabulary was trained and
> bench-confirmed 1:1 (see
> [`subsystems/VoiceSensor/VOICE-COMMAND-MAP.md`](subsystems/VoiceSensor/VOICE-COMMAND-MAP.md)). The
> smooth-motion engine + full gait catalog + IMU static leveling are implemented. The IK/gait/timing math
> and the integrated smart-pin ranging path remain flagged **⚠ verify** pending the bench playbook; the
> **live end-to-end voice→motion demo** (the dog executing each spoken command) is the current open bench
> step. The behavioral contract is specified in
> [`spec/P2-RobotDog-Specifications.md`](spec/P2-RobotDog-Specifications.md).

---

## 1. Settled decisions (quick reference)

| # | Decision | Rationale |
|---|---|---|
| D1 | **Gaits are latched modes** — FORWARD/TURN/BALANCE run until STOP or a new command | matches Freenove `condition()`; one message = sustained motion |
| D2 | **Backend is a pure executor** — owns only actuator safety (low-battery relax, joint limits); obstacle avoidance is *frontend* policy that emits STOP | keeps the control loop simple and predictable |
| D3 | **Command mailbox is latest-wins, single slot** — with a "reject if busy" rule for one-shot gestures | teleop semantics; no stale command backlog |
| D4 | **One cog owns the I²C bus** — IMU + servos + battery ADC all share one physical bus | only safe way to multi-master a single bus without a lock |
| D5 | **Backend concurrency is Spin2 v47 cooperative tasks** (coroutines), not separate cogs or interrupts | no preemption → no mid-transaction bus corruption; no lock |
| D6 | **A discrete-pin IO cog owns all non-I²C peripherals** — WS2812 LED (P8), buzzer (P10), ultrasonic (ECHO P9/TRIG P11). The top level *tasks* it via a mailbox and never blocks. | one owner *per pin* (smart-pin handoff across cogs is costly); consolidating the discrete-pin domain offloads the top level. Ultrasonic still behaves as a producer (publishes distance). Head-pan stays with the backend — it's a PCA9685/I²C channel. |
| D7 | **The IO cog runs non-blocking** — smart-pin pulse-measure ranging, timer/smart-pin buzzer, frame-stepped LED — so all three multiplex on one cog with **no jitter**. | P2 headroom + smart-pin timing offload mean ~1 % cog load; HC-SR04's own ~15–20 Hz echo physics caps ranging rate, not the cog. No reason to split ranging onto its own cog. |

---

## 2. Execution model: cogs

The P2 has 8 cogs running truly in parallel, no OS, communicating through shared hub RAM.
We partition the firmware across cogs by **resource ownership** — and *ownership* is the
operative word, because a hardware resource shared across cogs is the central hazard.

> **Two resource domains, each with a single owner cog:**
>
> 1. **The I²C bus** — PCA9685 servos (`0x40`), ADS7830 battery ADC (`0x48`), MPU6050 IMU
>    (`0x68`) all sit on one physical bus (P13/P15). A bus cannot be driven by two cogs
>    without a hardware lock, and `isp_i2c_singleton` holds bus state in shared DAT, so
>    **exactly one cog owns it** (*mandatory* — it is one shared resource).
> 2. **The discrete pins** — WS2812 (P8), buzzer (P10), ultrasonic (ECHO P9/TRIG P11). A *single pin*
>    cannot be cheaply shared across cogs: smart-pin mode is per-pin state and DIR/OUT OR
>    across cogs, so handing a pin between cogs means reconfiguring it. The rule is therefore
>    **one owner cog *per pin*.** Consolidating all discrete-pin devices into one **IO cog**
>    is *elective* (the pins are independent — you could split them), chosen for cog economy,
>    a single non-blocking service loop, and to offload the top level.

### Cog map

| Cog | Role | Owns (hardware) | Talks to others via |
|-----|---|---|---|
| **0** | **Comms / dispatch** | the command link (Wi-Fi/serial) — **today the voice dispatch loop** | writes command mailboxes A + B; reads telemetry + ping + **voice** |
| **1** | **Discrete-pin IO + voice** *(launched first)* | WS2812 LED (P8), buzzer (P10), ultrasonic (ECHO P9/TRIG P11), **I²C bus 2 (P18/P16): DF2301Q voice `0x64`** | reads command mailbox B; writes ping/IO + **voice** telemetry |
| **2** | **Backend body-control** | **I²C bus 1** (P13/P15): 13 servos, IMU, battery ADC | reads command mailbox A; writes telemetry |
| 3–7 | free | — | — |

> **Cog numbering:** `robot_dog_top` `cogspin`s the **IO cog first** (→ cog 1) and the backend
> **second** (→ cog 2), so the runtime map is **cog 1 = IO, cog 2 = backend**. The role/ownership
> split below is what matters; the integer labels simply follow launch order.

Two service cogs by resource domain (backend = I²C, IO = discrete pins), each fed by a
mailbox from the comms cog. Cogs 3–7 are spare. With cooperative tasks (§3) we are not forced
to spend a cog per concurrent activity, so we have ample headroom (e.g. a future
behavior/autonomy cog).

> **As-built (build 0.3.0):** `src/robot_dog_top.spin2` realizes this map — cog 0 runs its
> `main()` **persistent voice dispatch loop**, `cogspin`s `isp_io_controller.startWithVoice(8,10,11,9,18,16)`
> onto cog 1 (launched first) and `isp_dog_motion.start(13,15)` onto cog 2 (the 4-arg `io.start(...)`
> launches voice-off). Cog 1 also owns **I²C bus 2** (P18/P16) for the DF2301Q voice recognizer and polls
> it in its round-robin, publishing recognized CMDIDs. Cog 0 watches that voice telemetry and, on each
> fresh recognition, **maps the CMDID → a dog `CMD_*` via `voiceToDogCmd()`** (custom slots 5–21 plus
> built-in aliases 22/23) and posts it to mailbox A, gated on motion-completion — the seed of the real
> Wi-Fi/serial command link, which is still deferred (voice is today's command source). The legacy
> scripted concurrency self-test is preserved behind the `DEMO_ON_BOOT` build switch.

---

## 3. Concurrency inside the backend cog: cooperative tasks

The backend cog must do several things "at once" — consume commands, step the current
motion, sample the IMU and battery — **all while being the only cog touching the I²C bus.**
We do this with **Spin2 v47 cooperative multitasking** (verified to compile on PNut-ts
v1.55):

- `taskspin(id, method(), @stack)` launches a Spin2 method as a task (coroutine) with its
  own stack and PC. Up to 32 per cog.
- `tasknext()` yields round-robin to the next task. A task runs until *it* yields.
- `taskstop(id)` / `THISTASK` / `NEWTASK` manage lifetimes.
- The source file must begin with the **`{Spin2_v47}`** directive.

This is **cooperative coroutine multitasking**: there is no preemption. That property is
exactly what makes it safe on a shared bus —

> **A task is never interrupted mid-I²C-transaction.** It yields only at the `tasknext()`
> points it chooses, which we place strictly *between* complete transactions. So the bus
> stays coherent with **no lock**, and the "IMU is a producer, motion consumes a value"
> model is realized *within one cog*: `senseTask` produces, `motionTask` consumes, a hub
> mailbox sits between them.

### Backend tasks

| Task | Does | Yields |
|---|---|---|
| `dispatchTask` (main) | reads the command mailbox, sets mode / starts gestures, enforces safety floor | after each poll |
| `motionTask` | advances the current gait/gesture **one step** (the IK trajectory) and writes servos | after each step, between transactions |
| `senseTask` | reads IMU → attitude mailbox; periodically reads battery → telemetry | after each read, between transactions |

**Yield discipline (the contract):**
1. Never call `tasknext()` in the middle of an I²C transaction (between START and STOP).
2. Keep each task's run-between-yields short — cooperative preemption latency equals the
   longest such run, and a STOP command must be honored within one yield cycle.

**Caveat — cog-RAM overlap:** the per-task pointer table occupies cog registers
`$100..$11F`, building *downward* from `$11F`. That range **overlaps the inline-PASM
`ORG..END` region** (`$000..$11F`), and `isp_i2c_singleton` uses inline PASM. With our
handful of tasks (table uses only the top few longs) and small inline blocks this is fine,
but it is a real limit to watch if task count or inline-PASM size grows.

### The IO cog uses the same model — but simpler

The discrete-pin IO cog (cog 1) runs the same way: a non-blocking service loop (or Spin2 v47
tasks `ledTask` / `rangeTask` / `buzzerTask`) that, each pass, steps the LED engine (which advances
any animated base mode and any active single-shot cue), kicks/reads ranging when due, polls the
voice recognizer, and turns the buzzer off at its expiry tick. It is
**simpler than the backend** because each task owns its *own* pin — there is no shared bus, so
no re-entrancy to coordinate and no transaction-boundary yield discipline. The hard
requirement is only that every operation be non-blocking, which the **smart pins make true**:

| IO task | Non-blocking form |
|---|---|
| ranging | smart-pin pulse-width measurement — fire TRIG, read the hardware-measured echo later; the cog never busy-waits |
| buzzer | drive on + record off-tick (or a smart-pin tone); turn off when due |
| LED | step the LED engine one frame per pass (base mode + cue overlay); the ~210 µs transmit is the only atomic op |
| voice | poll the DF2301Q over I²C bus 2 (self-limited to ≥50 ms spacing); publish the recognized CMDID |

With timing offloaded to smart pins, the cog's compute load is ~1 %, so LED + ranging +
buzzer coexist with no jitter (per D7).

---

## 4. Data flow: producers, consumers, mailboxes

Everything crosses cogs through **single-writer hub mailboxes** — no cog reads another
cog's pins. Four regions, each with exactly one writer. Two are command mailboxes (comms →
each service cog), two are telemetry (each service cog → anyone):

```
' === COMMAND mailbox A  (writer: cog 0 comms → reader: cog 2 backend) ===
aCmdSeq   long      ' comms bumps this LAST, after args -> publishes the command
aCmdId    long      ' MOVE_FORWARD, TURN_LEFT, HEAD, ATTITUDE, PUSHUPS, RELAX, ...
aCmdArg   long[4]   ' speed / height / roll,pitch,yaw / head-angle, as the command needs
aAckSeq   long      ' backend sets = aCmdSeq when consumed (comms sees "accepted")

' === COMMAND mailbox B  (writer: cog 0 comms → reader: cog 1 IO) ===
bCmdSeq   long      ' comms bumps this LAST, after args -> publishes the command
bCmdId    long      ' LED_SOLID / LED_MODE / LED_BRIGHT / BUZZ_BEEP / BUZZ_TONE / RANGE_ENABLE
bCmdArg   long[4]   ' color / mode / level / ms / freq, as the command needs
bAckSeq   long      ' IO cog sets = bCmdSeq when consumed

' === TELEMETRY (writer: cog 2 backend → readers: anyone) ===
attRPY    long[3]   ' roll / pitch / yaw, centi-degrees (from senseTask)
battMv    long      ' pack millivolts (median, divider undone)
modeState long      ' IDLE / GAITING / GESTURE_BUSY / RELAXED / LOW_BATT
busyFlag  long      ' 1 while a one-shot gesture is running

' === IO TELEMETRY (writer: cog 1 IO → readers: anyone) ===
distMm     long     ' latest measured distance (the ultrasonic producer)
pingSeq    long     ' bumps each new reading (readers detect freshness)
ledBusy    long     ' 1 while a one-shot LED pattern is running
voiceCmdId long     ' latest recognized DF2301Q CMDID (raw; 0 = none yet)
voiceCmdSeq long    ' bumps once per recognition (readers detect a fresh command)
```

The **voice region mirrors the ranging producer**: `voiceCmdSeq` is the freshness counter (like
`pingSeq`) and `voiceCmdId` the value. The IO cog (cog 1) writes value-then-seq; the cog-0 dispatch
loop reads seq, and on advance reads the CMDID. The IO cog publishes the **raw** DF2301Q CMDID only —
it does **not** map CMDIDs to behavior or post commands (that is the cog-0 dispatch loop's job, via
`voiceToDogCmd()`), keeping it a pure peripheral server.

**Handshake (lock-free, single-writer/single-reader), used identically on both command
mailboxes:** the comms cog writes `*CmdArg[]` and `*CmdId` *first*, then bumps `*CmdSeq`
*last*. The service cog polls `*CmdSeq != *AckSeq`, reads the (now-stable) args, processes,
and sets `*AckSeq := *CmdSeq`. Writing the sequence word last guarantees the reader never
sees torn arguments. This is the cross-cog version of Freenove clearing `self.order=['',...]`
after consuming it.

---

## 5. Command routing

The Freenove `CMD_*` set sorts by *which resource owner* services it — one bucket per
service cog, plus pure queries the comms cog answers from telemetry:

| Bucket | Commands | Routed to | Resource |
|---|---|---|---|
| **Motion / posture → mailbox A** | `MOVE_*`, `TURN_*`, `BALANCE`, `HEIGHT`, `HORIZON`, **`HEAD`**, `ATTITUDE`, `RELAX`, `CALIBRATION` + gestures (push-ups, hello) | cog 2 backend | I²C bus |
| **LED / buzzer / sonic → mailbox B** | `LED`, `LED_MOD`, `BUZZER`, `SONIC` (enable/rate) | cog 1 IO | discrete pins |
| **Query (comms-local)** | `POWER`, `WORKING_TIME` | cog 0 answers from telemetry / IO telemetry | — |
| **Voice (producer → cog 0)** | recognized DF2301Q CMDID (read via `getVoiceCmdId()`/`getVoiceSeq()`) | cog 1 IO publishes; **cog 0 dispatch loop** maps via `voiceToDogCmd()` → mailbox A | I²C bus 2 |

`CMD_HEAD` lands in the **backend** bucket because the head-pan servo is PCA9685 ch 15 — on
the backend's bus, not a discrete pin. A "look around and range" behavior is therefore a
**backend ⇄ IO collaboration**: the backend pans the head, the IO cog reports distance, and
the fusion (angle ↔ distance) is comms/behavior policy (per D2). `SONIC` distance and `POWER`
voltage are read by the comms cog from the IO and backend telemetry regions respectively.

---

## 6. Motion model & backend state machine

Two classes of motion, distinguished by lifetime:

- **Latched / cyclic** (FORWARD, BACKWARD, sidestep, TURN, BALANCE): the command sets a
  *mode*. `motionTask` repeats the gait cycle every step until a different command or STOP
  arrives (D1). One message → sustained walking.
- **One-shot** (PUSHUPS, HELLO, RELAX, a HEIGHT/HORIZON/ATTITUDE step, CALIBRATION): runs to
  completion with `busyFlag = 1`, then returns to IDLE / last stance. New gestures are
  rejected while busy (D3).

Backend loop, expressed as cooperative tasks:

```
dispatchTask:
  repeat
    if cmdSeq <> ackSeq                      ' new intent published
      latch cmdId/cmdArg;  ackSeq := cmdSeq
      case cmdId
        MOVE_*/TURN_*/BALANCE : mode := that gait          ' latched (D1)
        HEIGHT/HORIZON/ATTITUDE/HEAD/RELAX : start one-shot move
        gesture (PUSHUPS/HELLO) : if not busyFlag -> start; else ignore (D3)
        MOVE_STOP : mode := IDLE (ease to neutral stance)
    enforce safety floor: if battMv < cutoff -> force RELAX, modeState := LOW_BATT  (D2)
    tasknext()

motionTask:
  repeat
    case mode
      GAIT_*  : compute next per-leg XYZ for this gait step; leg[i].moveToXYZ(...)   ' preemptible each step
      GESTURE : advance gesture trajectory one step; if done -> mode := IDLE, busyFlag := 0
      IDLE    : hold stance
    tasknext()

senseTask:
  repeat
    read IMU -> attRPY mailbox
    every N passes: read battery -> battMv
    tasknext()
```

Because `motionTask` checks the latched `mode` (set by `dispatchTask`) every step, a STOP or
new command preempts a running gait within one yield cycle — responsive, without preemption.

IK ownership: `isp_leg.moveToXYZ(x,y,z)` does the per-leg inverse kinematics
(`coordinateToAngle` + side-mirror + that leg's calibration); `isp_dog_motion` generates the
gait/pose target coordinates and drives all four legs. See [`../src/README.md`](../src/README.md) §3.

### 6.1 Smooth-motion engine (implementation guide)

**Quality bar:** Freenove's own demo videos look **wobbly/staccato** — a platform artifact
(single-threaded Python on a Pi, blocking loops sharing the CPU with camera/streaming/server, no
RTOS, linear steps). We aim to clearly **beat that look** by exploiting parallelism + determinism the
Pi can't: a dedicated motion cog on a CT-timed fixed-rate loop (no OS jitter), CORDIC IK ~free (fine
interpolation + per-frame Cartesian paths + ease-in/out), smart pins offloading PWM/serial/ultrasonic,
and real-time IMU balance on a parallel cog. (Staccato = timing, ours to win; residual wobble is
mechanical/dynamic — gait tuning + IMU balance.)

**Goal:** regular, fluid motion with **no gaps or snaps** between moves. Today's code *snaps*
(`isp_i2c_pca9685_servo.writePosition` writes once; `standPose`/`relaxPose` set final angles in one
shot). The engine below replaces that. **`isp_leg` is the IK/angle provider; `isp_dog_motion` is the
conductor** — coordination (timing, synchronization) lives at the **body** level, because
synchronized, simultaneous multi-leg motion needs one shared timebase.

**The model**
- **One fixed-rate frame loop** (`motionTask`, CT-based ~50 Hz). Every frame it advances the motion
  and writes **all 12 leg joints + head together** — never one leg at a time.
- **Synchronized joint timing (within a leg):** a point-to-point move sets each joint's *target*
  (via IK), then all joints interpolate from current→target over the **same duration** sharing one
  normalized `s: 0→1`. Each joint moves at its own *relative* speed (distance ÷ T) but they **start
  and arrive together**. Apply an **ease-in/out** S-curve on `s` so they accelerate/decelerate.
- **All legs together (across legs):** one shared `s` (poses) or one shared gait phase (gaits)
  drives every leg the same frame → the whole body arrives together.
- **Two interpolation spaces:**
  - *Joint-space lerp* — cheap; fine for poses (stand/relax/sit/transitions). Foot path is slightly
    curved (invisible).
  - *Cartesian foot-path + per-frame IK* — for gaits, where the foot must trace a defined path
    (flat stance, arc swing). The CORDIC makes per-frame IK affordable.
- **Blending:** when a new command arrives, ease from the *current* pose into the next pose/gait —
  no stop-and-restart. This is what removes the gaps.

**What we PORT from the reference (most of it) — `REF/FNK0050-Code/Server/Control.py`:**
- `run()` (≈ line 97): IK for all 4 legs from `point[]`, apply per-leg calibration + the side
  mirror, clamp 0–180, **write all 12 servos**. This is our per-frame "write all legs" — `point[]`
  ⇄ our body-held target/current arrays.
- `stop()` (≈ line 337): `delta = (target − current)/N`, loop N× adding delta and calling `run()` —
  the **synchronized N-step point-to-point lerp** (all legs together). Our pose moves use this shape.
- Gaits `forWard`/`backWard`/`turnLeft`/`turnRight`/`setpLeft`/`setpRight` (≈ line 284+): **Cartesian
  foot trajectories** (`X=12·cos(phase)`, `Y=6·sin(phase)+height`, foot-lift clamp, diagonal pairs
  180° apart), phase stepped by **`self.speed`** (the smoothness/speed knob). The full gait catalog
  is here to port.
- `changeCoordinates()` (≈ line 244): maps a gait's X/Y/Z into the 4-leg `point[]` mirror/diagonal
  pattern. `checkPoint()` (≈ line 122): reachability guard (leg length 25–130 mm) — port as a safety
  clamp.

**What is OURS to invent (the P2 real-time layer):**
- Freenove uses **blocking Python `for` loops** (timing = loop speed; `time.sleep` commented out).
  We run the same math on a **non-blocking, fixed-rate cooperative frame** in `motionTask` so the IO
  and comms cogs stay live and motion timing is deterministic.
- **Mailbox-driven, interruptible/blendable** motion (Freenove finishes a gait loop before the next
  command; ours blends/redirects mid-motion via the latched `mode` + current-pose blend).
- **Ease-in/out** curves (Freenove steps are *linear* / constant-speed) — our refinement.

**Refactor path:** give `isp_dog_motion` body-level `current[]`/`target[]` joint (or foot-XYZ) arrays
and a `speed`/duration; turn `motionTask` into the fixed-rate interpolator that writes all legs each
frame (a `run()`-equivalent); express poses as N-step lerps and gaits as Cartesian phase trajectories
— porting `Control.py`'s math. Build this **before** authoring the full motion catalog, since it
changes how every motion is issued.

### 6.2 Smooth-motion engine (as-built, build 0.1.1)

The §6.1 guide is realized in `src/isp_dog_motion.spin2`. What the engine actually does:

- **Body-level state.** Foot targets in mm, leg order **FL=0 / BL=1 / FR=2 / BR=3**: `curX/Y/Z[]`
  (where the feet are now), `tgtX/Y/Z[]` (where the active move eases to), `startX/Y/Z[]` (the lerp
  anchor at move start), plus head `cur/tgt/start`. `setCur()` writes a foot's *current* directly
  (gaits/gestures); `setLegTarget()` sets a *target* (poses).
- **Fixed-rate frame loop.** `motionTask` is CT-gated at `FRAME_HZ = 50` (wrap-safe `getct()`
  deadline). Each due frame calls `advanceFrame()` → `advanceGait` / `advanceGesture` / `stepPose`
  by mode, then `tasknext()` so dispatch/sense keep running. Servo writes always **complete before
  the yield** — the bus stays coherent with no lock.
- **Eased poses.** `stepPose()` lerps all 13 joints from `start→tgt` over `moveFrames` sharing one
  ease factor `easeFactor()` (smoothstep `3s²−2s³`, fixed-point `EASE_ONE = 4096`) via `lerpFix()`.
  `armMove()` snapshots `start := cur` and arms the move; `beginPoseMove()` adds the head-holds.
- **Commit + guard.** Every frame ends in `commitCur()`: `guardReach()` clamps each foot to the
  reachable shell (`REACH_MIN_MM`/`REACH_MAX_MM = 25/130`, ported `checkPoint`) then `writeLegs()`
  drives all four legs. Belt-and-suspenders with `isp_leg`'s 0–180° clamp.
- **Blending.** Poses snapshot `start := cur` from the live pose, so a new command eases from
  wherever the body is — no stop-and-restart. `CMD_STOP` eases to neutral, interrupting a gait.
- **Gaits (catalog).** `advanceGait()` dispatches on `gaitKind` → `gaitLinearFwd`
  (forward/backward), `gaitSidestep` (step L/R), `gaitTurn(turnSign)` (turn L/R, X/Z coupled).
  Diagonal pairs A={FL,BR}, B={BL,FR} 180° apart; sinusoid is already smooth so no easing is layered
  on. `startGait(kind,dir,speedArg)` latches the mode and signed phase step; `setGaitSpeed` applies
  the **arg0 speed knob** (`0`=default `GAIT_STEP_DEG=15`, else clamp `3..45`). Mapped onto the
  loaded-rear-crouch neutral: stride X stays centred on 0 (Z=±`STANCE_LATERAL_MM`), and each foot's
  lift is clamped to its **own** planted floor — `plantFloor(idx,lift)` swings up off
  `neutralFootY(idx)` (front 95 / rear 85), so the front-vs-rear height split survives walking
  instead of collapsing to one shared height. Freenove's absolute offsets are **not** applied.
- **Hello gesture.** `advanceHello()` eases the FR foot out over `HELLO_LEADIN_FRAMES=8` (no start
  snap), oscillates with the `qsin` wave, then `finishGesture()` eases back to stand. `busyFlag`
  reject-while-busy preserved (D3).
- **Neutral stance (single source of truth).** Poses and gaits share one neutral — the **loaded-rear
  crouch** — through `neutralFootTarget(idx)` → `(fx,fy,fz)` (and `neutralFootY(idx)` for just the
  planted floor). Front feet stand at `NEUTRAL_FRONT_Y_MM=95`/X=0; rear feet fold deeper to
  `NEUTRAL_REAR_Y_MM=85` and tuck back to `NEUTRAL_REAR_X_MM=−12` for a ~60:40 forward weight bias.
  The gait lead-in, the HELLO lean-out, and the push-up lead-in all reach it the same way
  (`easeAllToNeutral`); `STAND_HEIGHT_MM=99` is now only the *tall* SIT/BOW/PARADE reference. See
  [`spec/P2-RobotDog-Specifications.md`](spec/P2-RobotDog-Specifications.md) §2.2.
- **Static leveling.** `neutralFootTarget` folds each leg's foot-Y trim from
  `isp_calibration.stanceTrimY()` into the crouch (`setLevelStandTargets`, used by `standPose` and
  `seedStand`). See [`spec/P2-RobotDog-Specifications.md`](spec/P2-RobotDog-Specifications.md) §5.
- **Power-on.** `seedStand()` snaps to neutral once (no prior pose to blend from) — the only snap.

> The engine owns interpolation at the **body** level; the per-servo S-curve slew in
> `isp_i2c_pca9685_servo` is intentionally **not** used (it cannot share one timebase across 13
> joints). `isp_leg` stays the IK/angle provider.

### 6.3 Motion progression: from Freenove-equivalent toward dog-like (and beyond)

This driver is deliberately walking a path **from "it moves" to "it moves like a dog,"** and the *how*
and *why* of each stage matter as much as the code:

- **Stage 0 — Freenove baseline (the reference).** The upstream Python drives joints to angles via
  simple **sinusoid gaits**, **snap-to-pose** (no easing), essentially **2-D** (fore-aft motion in the
  sagittal plane), body held rigidly level. It works, but it reads **staccato and robotic** — symmetric,
  planar, and the body never participates.

- **Stage 1 — smooth-motion engine (build 0.1.1).** We replaced snap-then-wait with a **fixed-rate,
  eased, blendable** engine (§2, §6.2): all joints share one timebase and one ease factor, so they start
  and arrive together and transitions are gapless. The Freenove *trajectory shapes* were ported onto our
  verified neutral — so motion became **fluid**, but it was still fundamentally the 2-D sinusoid.

- **Stage 2 — honest range + kinematic model (2026-06).** We **corrected the servo µs mapping**
  (500–2500 µs = full 0–180°, up from a compressed ~126°), **measured the real leg kinematics** (axes,
  centers, per-joint drivable limits — spec §8), and added **per-joint clamps**. *Why this matters for
  motion:* it unlocks the **full workspace** — especially the **coxa's lateral-vertical sweep**, which
  the old mapping hid, and which is exactly the axis a 2-D gait never touches.

- **Stage 3 — dog-like motion studies (current/next).** Study real canine locomotion and map it onto
  our *achievable* range: **asymmetric foot-trajectory arcs** (quick lift, long low swing, soft plant),
  **joint phasing & duty factor**, **body roll/bob**, and **using the coxa for 3-D leg motion** instead
  of planar sinusoids. *Why ours looks robotic:* the Freenove shapes are symmetric, planar, and static;
  dogs are **asymmetric, 3-D, and dynamic.** Each recommendation is constrained to what the measured
  hardware can actually do.

- **Stage 4 — active IMU balance (longer-term).** Close the loop: react to disturbances in real time
  (step onto something, drifting out of balance) by adjusting foot placement / shifting CoG, or stopping
  to avoid a tip. Today the IMU is used only for **static** leveling (§5); this layers **closed-loop
  robustness** on top once the open-loop motion is dog-like. See `DOCs/FUTURE-DIRECTIONS.md` §5.

Each stage **builds on the last**: the engine (1) is the fluid substrate; the model (2) is the workspace
+ safety; the studies (3) supply the trajectories; the IMU (4) supplies robustness.

---

## 7. Startup / init sequence

1. **Cog 0** boots (Spin top object): debug output via the built-in `DEBUG()`, parse config.
2. Cog 0 launches **cog 1** (IO) *first*. Cog 1 owns its discrete pins: brings up the LED engine
   (`isp_led_engine` over `isp_led_ring`, idle/boot pattern), idles the buzzer, configures the
   ultrasonic smart pins and begins periodic ranging — publishing `distMm`/`pingSeq` — and (with
   `startWithVoice`) brings up **I²C bus 2** and probes the DF2301Q, publishing `voiceCmdId`/`voiceCmdSeq`.
   Then it services mailbox B.
3. Cog 0 launches **cog 2** (backend). Cog 2:
   - `isp_i2c_singleton.setup()` (it now owns the bus),
   - `present()`-checks PCA9685 / ADS7830 / MPU6050; reports any missing device via telemetry,
   - configures the PCA9685 (PWM freq), reads IMU calibration, eases legs to a safe stance,
   - `taskspin`s `motionTask` and `senseTask`, then runs `dispatchTask`.
4. Steady state: cog 0 runs the voice dispatch loop (reads voice telemetry, maps CMDID→behavior,
   posts to mailboxes A + B, renders telemetry); cog 2 runs motion/sense; cog 1 runs LED/buzzer/
   ranging/voice.

---

## 8. Safety behaviors (backend-owned, per D2)

- **Low battery:** when `battMv` < 6.4 V (`isp_battery_monitor`), the backend forces RELAX
  and sets `modeState = LOW_BATT` regardless of frontend commands. Mirrors Freenove's
  auto-shutdown. The **IO cog** can pulse the ring red by *reading* `modeState` from the
  backend telemetry region — a status display driven entirely by telemetry, no command needed.
- **Joint limits:** `isp_i2c_pca9685_servo` clamps every move to its configured µSec range;
  `isp_leg` clamps IK results to legal angles. Out-of-range targets are clamped, not faulted.
- **Obstacle avoidance is *not* here.** The backend does not auto-stop on a close ping
  reading; it stays a pure executor. Turning "obstacle too close" into a STOP is frontend
  policy (it reads the ping mailbox and emits `MOVE_STOP`).

---

## 9. Open items / to verify on hardware

**Resolved since the original draft:**

- ✅ **Leg ↔ channel ↔ side mapping** — **verified on hardware 2026-06-01** (FL=4/3/2, BL=7/6/5,
  BR=8/9/10, FR=11/12/13, head=15); see README §3.
- ✅ **IO-cog refactors + launch** — `isp_hcsr04` has a non-blocking **smart-pin** ranging path
  (`startSmart`/`firePing`/`echoReadyMm`), the buzzer is non-blocking (auto-off tick), and the LED
  is frame-stepped — all three multiplex on `isp_io_controller` (per D7). The **top-level cog
  launch + mailbox B are assembled** in `src/robot_dog_top.spin2` (cog 0 is now the **voice dispatch
  loop**, the seed of the command source — the real Wi-Fi/serial link is still deferred).
- ✅ **Voice CMDID→behavior mapping** — `voiceToDogCmd()` is fully wired: custom slots 5–21 → the
  matching `CMD_*`, plus built-in aliases 22 (`Go Forward`) / 23 (`Retreat`). The 17-word vocabulary
  was trained in one uninterrupted session and cataloged 1:1 (`test_voice_map`). Authoritative map:
  `subsystems/VoiceSensor/VOICE-COMMAND-MAP.md`.
- ✅ **Command-driven LED engine** — `isp_led_engine` is the sole owner of the WS2812 ring; callers
  request sustained **base modes** (off/solid/wipe/chase/rainbow/rainbow-cycle/rainbow-breathe) and
  **single-shot cues** (`blink`) that preempt latest-wins and revert to the base. Fixed the earlier
  multi-writer race; per-mode pacing (30 ms smooth / 130 ms marching). The IO cog steps it each pass.

**Still to verify on the bench (see the verification playbook):**

- **Live end-to-end voice→motion** — the dog actually executing each spoken command through the
  full dispatch→gate→backend path (the mapping is code-complete and the vocabulary is bench-trained;
  the integrated voice→motion run is the headline open bench step).
- **Full LED feedback scheme** — only the basic green recognition cue is wired today; the intended
  "spinning green = acting / red = refused-or-gated / off = idle" scheme is not yet driven from the
  dispatch loop (now easy via the LED engine).
- **Smooth-motion quality** — stand/sit/relax transitions gapless and blends clean; the "beat
  Freenove's staccato" bar; each gait + the speed arg behave.
- **Integrated smart-pin ranging** — the non-blocking path, first exercised by the integrated top,
  produces fresh `pingSeq` while a gait + LED + beep run (D7 no-stutter).
- **IMU static leveling** — measure → store → apply → residual ≈ 0; capture the stance-trim values
  (default 0 today).
- **Servo write budget:** the seed `write9685OffOnWords` does `waitms(1)` per channel → ~13 ms
  for a full-body update. Batch leg channels 2–13 in one PCA9685 auto-increment burst to
  collapse this; sets the control-loop ceiling vs. the 50 Hz frame rate.
- **IMU rate vs. servo cadence:** decide whether `senseTask` reads the IMU faster than the
  full-body write rate (read-often / write-on-change) or runs the whole loop at one rate.
- **Cooperative yield granularity:** tune gait-step size so STOP latency stays small.
- **`{Spin2_v47}` task table vs inline-PASM** (`$100..$11F` overlap) — watch as task count
  or inline-PASM grows.
- **WS2812 bit timing** in `isp_ws2812` matches `REF jm_rgbx_pixel` (fixed 1.25 µs cell,
  400/800 ns high) — only the strip variant remains to confirm (WS2812 350/700 vs WS2812B 400/800).

---

*Companion document:* [`../src/README.md`](../src/README.md) — static architecture (objects,
tiers, files, pins). *Hardware authority:* `P2-platform/P2_MIGRATION_WIRING.md`, `RPI_GPIO_USAGE.md`.

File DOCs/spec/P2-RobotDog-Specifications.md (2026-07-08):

# P2 Robot Dog — Firmware Specifications

The behavioral contract of the Robot Dog (FNK0050) P2 firmware: the smooth-motion engine, the
gait catalog and its speed knob, the three-cog command + telemetry interface (mailboxes A and B),
and the IMU static-leveling behavior. This is the **as-built spec** for build 0.1.2 — what the
firmware *does* and how a caller drives it.







> **Scope & authority.** This document owns the *firmware behavioral contract*. The **static**
> object/tier map lives in [`../../src/README.md`](../../src/README.md); the **runtime** cog/task
> model and mailbox protocol live in
> [`../P2_FIRMWARE_THEORY_OF_OPS.md`](../P2_FIRMWARE_THEORY_OF_OPS.md) (ToOps); hardware pin/rail
> facts live in [`../P2-platform/P2_MIGRATION_WIRING.md`](../P2-platform/P2_MIGRATION_WIRING.md). Where they overlap, those
> documents win for their domain and this one cites them.
>
> **Verification status.** All firmware here **compiles clean** (PNut-ts, full sweep). Behavioral
> correctness is proven on the bench via the verification playbook, not by an automated runner —
> items needing the bench are flagged **⚠ bench** inline.

---

## 1. Overview

The firmware runs as **three cogs** (ToOps §2): a comms/dispatch cog (cog 0), the discrete-pin IO cog
(cog 1, launched first — owns the discrete pins + voice bus), and the backend body-control cog (cog 2,
the sole I²C bus-1 owner). A caller on cog 0 drives the robot **only** through two hub mailboxes —
never by touching a bus or pin:

- **Mailbox A → backend** (`isp_dog_motion`): motion, posture, head, gestures; reports attitude,
  battery, mode.
- **Mailbox B → IO** (`isp_io_controller`): LED ring, buzzer, ultrasonic ranging; reports distance,
  ping sequence, LED-busy.

`src/robot_dog_top.spin2` is the first object to assemble all three cogs; it runs the **persistent
voice dispatch loop** — voice is today's command source, a stand-in until the real Wi-Fi/serial command
link is built (the legacy scripted demo is preserved behind `DEMO_ON_BOOT`).

---

## 2. The smooth-motion engine

**Quality bar:** beat Freenove's wobbly/staccato look (ToOps §6.1). The engine owns body-level
interpolation on one shared timebase so all joints start and arrive together — no per-servo slew,
no snaps, no gaps.

### 2.1 Contract

| Property | Value | Notes |
|---|---|---|
| Frame rate | **50 Hz**, CT-gated | `FRAME_HZ`; one timebase for all 13 joints |
| Ease curve | smoothstep `3s² − 2s³` | fixed-point, `EASE_ONE = 4096`; shared `s: 0→1` |
| Pose duration | **30 frames** (~0.6 s) | `POSE_FRAMES` |
| Head-pan duration | **20 frames** (~0.4 s) | `HEAD_FRAMES` |
| Reachability guard | foot **25–130 mm** from hip | `REACH_MIN_MM`/`REACH_MAX_MM`; ported Freenove `checkPoint` |
| Write discipline | all legs + head per frame, between I²C transactions | never one leg at a time; never yields mid-transaction (ToOps §3) |

- **Poses** (stand/relax/sit/head) ease point-to-point: the move snapshots `start := current`,
  sets `target`, and `stepPose()` lerps every joint over the same frame count with the shared ease
  factor.
- **Gaits and gestures** write the four feet directly each frame from a Cartesian sinusoid (already
  smooth, so no easing is layered on) and commit through the same per-frame reachability guard.
- **Blending:** a new command eases from the *live* current pose — no stop-and-restart. `CMD_STOP`
  eases to the neutral stance, interrupting any running gait.
- **Power-on** seeds the neutral stance once (`seedStand`, a deliberate snap — there is no prior
  pose to blend from).
- **Reachability guard** scales any out-of-range foot back onto the reachable shell; the 0–180°
  servo-angle clamp in `isp_leg` is the belt-and-suspenders second line.

### 2.2 Neutral stance — the loaded-rear crouch

All trajectories are mapped onto a single **loaded-rear-crouch neutral** — the one source of truth
every pose eases to/from and every gait oscillates around, exposed by `neutralFootTarget(idx)` (and
`neutralFootY(idx)` for just the per-leg planted floor). It is **per-leg**, not one shared height:

| Legs | Foot X | Foot Y (extension) | Foot Z |
|---|---|---|---|
| Front (FL/FR) | `NEUTRAL_FRONT_X_MM = 0` (under the shoulders) | `NEUTRAL_FRONT_Y_MM = 95` | ±`STANCE_LATERAL_MM = 10` (L +, R −) |
| Rear (BL/BR) | `NEUTRAL_REAR_X_MM = −12` (tucked toward the tail) | `NEUTRAL_REAR_Y_MM = 85` (folds deeper) | ±`STANCE_LATERAL_MM` |

The rear folds deeper (smaller Y) and tucks back (−X) against the `HALF_BODY_LENGTH_MM = 136` lever to
bias the weight **~60:40 forward** — a visibly loaded hindquarter, the dog-like resting crouch. All
four `NEUTRAL_*` are bench-tune knobs. `neutralFootTarget` folds each leg's static leveling trim
(`cal.stanceTrimY`) into Y, so it returns the level-corrected target. **Bench pitch decision (open):**
the crouch is meant to sit a touch nose-up; at leveling re-measure we either keep that intended
nose-up (leave the pitch trim ≈ 0) or flatten it (paste the measured pitch) — see §5.

`STAND_HEIGHT_MM = 99` is **no longer the neutral** — it is retained only as the *tall* stand
reference for the deliberately-tall sub-poses (SIT front, BOW rear, PARADE REST). Freenove's absolute
`changeCoordinates` offsets (+10 X, ±10 Z) are **not** applied — only its trajectory amplitudes and
phase shapes are ported.

---

## 3. Gait catalog

All gaits are **trotting**: diagonal pairs **A = {FL, BR}** and **B = {BL, FR}** run 180° out of
phase. Each is a **latched mode** (D1) — one command sustains it until `CMD_STOP` or another
command. Trajectories are ported from `REF/.../Control.py` onto the loaded-rear-crouch neutral
(§2.2); each foot's lift is clamped to its **own** planted floor (`Y ≤ neutralFootY(idx)` via
`plantFloor`), so a mixed diagonal pair keeps the front-vs-rear height difference while walking.
Stride X stays centred on 0 (the rear −X tuck is a static-neutral property, not part of the walking
trajectory).

| Gait | Command | Trajectory (per foot) | Amplitudes |
|---|---|---|---|
| Forward | `CMD_FORWARD` | X = A·cos(φ) stride, Y = L·sin(φ)+h lift | X `GAIT_X_AMPL_MM=12`, lift `GAIT_LIFT_MM=6` |
| Backward | `CMD_BACKWARD` | same shape, phase **decrements** | same as forward |
| Turn left | `CMD_TURN_LEFT` | X = A·cos(φ), Z coupled to X (yaw), Y = L·sin(φ)+h | XZ `TURN_XZ_AMPL_MM=3`, lift `TURN_LIFT_MM=8` |
| Turn right | `CMD_TURN_RIGHT` | turn-left mapping with X amplitudes negated | same |
| Step left | `CMD_STEP_LEFT` | X = 0, Z = A·cos(φ) added to lateral, Y = L·sin(φ)+h | Z `STEP_Z_AMPL_MM=10`, lift `STEP_LIFT_MM=5` |
| Step right | `CMD_STEP_RIGHT` | same shape, phase **decrements** | same as step-left |

> Each `Y = L·sin(φ)+h` uses **h = that leg's `neutralFootY(idx)`** (front 95 / rear 85, plus the
> leveling trim) — the per-leg planted floor, not one shared height; `plantFloor` clamps each foot to
> its own floor.
>
> ⚠ bench — the turn XZ amplitude (3 mm) is small but faithful to the reference; tune on the bench.

### Speed knob

Every gait takes **`arg0` = phase step (degrees/frame)** — the speed/smoothness knob. `0` selects
the default `GAIT_STEP_DEG = 15`; any other value is clamped to **`GAIT_SPEED_MIN..MAX = 3..45`**.
Smaller = slower and smoother (more frames per stride).

---

## 4. Command & telemetry interface

### 4.1 Mailbox A — backend (`isp_dog_motion`)

**Post:** `dog.postCommand(commandId, arg0, arg1, arg2, arg3)` — latest-wins, single slot; args are
written first and the sequence word last (lock-free publish, ToOps §4).

| Command | Value | arg0 | Effect |
|---|---|---|---|
| `CMD_STOP` | 1 | — | ease to neutral stance, mode IDLE |
| `CMD_FORWARD` | 2 | speed | latched forward gait |
| `CMD_RELAX` | 3 | — | ease to tucked rest, mode RELAXED |
| `CMD_STAND` | 4 | — | ease to neutral stance, mode IDLE |
| `CMD_SIT` | 5 | — | ease to sit (rear lowered) |
| `CMD_HELLO` | 6 | — | one-shot wave (eased in/out); rejected while busy (D3) |
| `CMD_HEAD` | 7 | angle° | pan head (eases when idle; immediate during a gait) |
| `CMD_BACKWARD` | 8 | speed | latched backward gait |
| `CMD_TURN_LEFT` | 9 | speed | latched turn-left |
| `CMD_TURN_RIGHT` | 10 | speed | latched turn-right |
| `CMD_STEP_LEFT` | 11 | speed | latched sidestep-left |
| `CMD_STEP_RIGHT` | 12 | speed | latched sidestep-right |

> **One-shot gestures.** Beyond the motion set above, the backend exposes one-shot gesture
> commands (`CMD_HELLO`, `CMD_SHAKE`, `CMD_SALUTE`, `CMD_BOW`, …), each eased in/out and rejected
> while busy (D3). Behaviors to note:
> - **`CMD_BOW`** drops the front chest **and raises the head** (`BOW_HEAD_UP_DEG`, eased in
>   lock-step with the chest) so the snout clears the surface; on the **`BOW→STAND`** that leaves the
>   bow, the head **eases back to the angle it held at bow entry** (snapshotted into `savedHeadDeg`),
>   so a one-shot bow returns the head where it started — a deliberate `CMD_HEAD` posted while bowed
>   still wins.
> - The **paw gestures** (`CMD_SHAKE` / `CMD_SALUTE`) first **rebalance into a leaned sit** —
>   shifting the CoG into the FL/BL/BR tripod (`PAW_LEAN_LAT_MM`) — **before** lifting the front-right
>   paw; when the paw lowers they **ease the lean back out to a level, centered seated posture** (the
>   `GST_LEVEL_OUT` stage) so the gesture ends balanced, not frozen in its terminal tilt, and holds
>   that level sit until a later `CMD_STAND`/`CMD_STOP`.
> - **`CMD_HELLO`** waves the front-right foot with a **lift bias** (`HELLO_LIFT_MM`) so the whole
>   wave floats above the surface and the foot never contacts the floor, then re-levels to the neutral
>   stand on its way out.
>
> ⚠ bench — lean, head-raise, and wave-lift magnitudes are bench-tunable.

**Telemetry (getters, safe from any cog):**

| Getter | Returns |
|---|---|
| `getModeState()` | `MODE_IDLE/GAITING/GESTURE_BUSY/RELAXED/LOWBATT` (0–4) |
| `getBatteryMilliVolts()` | pack millivolts (median, divider undone) |
| `getAttitude()` | `pitchDeg, rollDeg` (accelerometer tilt; **pitch = fore/aft, roll = lateral** — see §5 axis mapping) |
| `isBusy()` | TRUE while a one-shot gesture runs |

### 4.2 Mailbox B — IO (`isp_io_controller`)

**Post:** `io.postCommand(commandId, arg0, arg1, arg2, arg3)` — same latest-wins/publish contract.

| Command | Value | arg0 | Effect |
|---|---|---|---|
| `IO_LED_SOLID` | 1 | `$RRGGBB` | all pixels one color (static) |
| `IO_LED_MODE` | 2 | ring mode | set display mode; animated modes self-step |
| `IO_LED_BRIGHT` | 3 | 0–255 | brightness |
| `IO_LED_OFF` | 4 | — | blank the ring |
| `IO_BUZZ_BEEP` | 5 | ms | non-blocking beep (auto-off) |
| `IO_BUZZ_OFF` | 6 | — | silence |
| `IO_RANGE_ON` | 7 | interval ms (0=default) | start periodic ranging |
| `IO_RANGE_OFF` | 8 | — | stop ranging |

Ring modes (`IO_LED_MODE` arg0): `OFF/SOLID/WIPE/CHASE/RAINBOW/RAINBOW_CYCLE` (0–5); ≥ WIPE are
animated. The three color modes (`SOLID`/`WIPE`/`CHASE`) paint in a **default white** until an
`IO_LED_SOLID $RRGGBB` overrides the color, so they render visibly from a fresh boot (before any
color is posted); `RAINBOW`/`RAINBOW_CYCLE` self-color via the wheel.

**Telemetry:**

| Getter | Returns |
|---|---|
| `getDistanceMm()` | latest distance, mm (`NO_ECHO = −1` if the last ping found nothing) |
| `getPingSeq()` | ranging sequence (bumps each reading → readers detect freshness) |
| `isLedBusy()` | TRUE while an animated LED mode runs |
| `getVoiceCmdId()` | latest recognized **raw DF2301Q CMDID** (0 = none yet); see §4.4 |
| `getVoiceSeq()` | voice-recognition sequence (bumps once per recognition → readers detect freshness) |
| `voicePresent()` | TRUE if the DF2301Q ACKed its probe at `startWithVoice()` (voice bus live this build) |

> ⚠ bench — the IO cog's **non-blocking smart-pin ranging path** (`startSmart`/`firePing`/
> `echoReadyMm`) is first exercised integrated by `robot_dog_top`; previously only the blocking
> menu path ran. Confirm live ranging (fresh `pingSeq`) on the bench.

### 4.3 Three-cog launch

`robot_dog_top.main()` runs on cog 0 and:

1. `cogspin` **IO** *(first)* → cog 1: `io.startWithVoice(WS2812=8, BUZZER=10, TRIG=11, ECHO=9, VSCL=18, VSDA=16)`
   — owns the discrete pins **and I²C bus 2** for voice (the 4-arg `io.start(...)` launches voice-off).
2. `cogspin` **backend** → cog 2: `dog.start(SCL=13, SDA=15)` (inits, gyro-cals, stands).
3. Enters the **persistent dispatch loop** (§4.4): watch the IO cog's voice telemetry and hand
   recognized commands to mailbox A, gated on motion-completion. The legacy scripted concurrency
   self-test (LED animation + live ranging + a gait + a beep at once, D7) is preserved behind the
   `DEMO_ON_BOOT` build switch. Pins per the as-built map (ToOps §2 / wiring §3, §3a).

### 4.4 Voice recognition (DF2301Q, 2nd I²C bus)

A **DFRobot DF2301Q "Gravity" offline voice recognizer** (SKU SEN0539, I²C `0x64`) — a **P2-only
addition**, not part of the stock Freenove kit — gives the dog a spoken command source. The vendor
driver kit lives in `src/` (`isp_voice_recognizer`, `isp_voice_command_names`) and is documented under
[`../subsystems/VoiceSensor/`](../subsystems/VoiceSensor/) (USER-GUIDE, COMMAND-CATALOG); this spec
covers only how it integrates.

**Bus & ownership.** The module sits on a **separate 2nd I²C bus** (P18 = SCL, P16 = SDA), **owned by
the IO cog** (cog 1) — bus 1 (backend/cog 2) and bus 2 (IO/cog 1) never cross cogs. The DF2301Q
**clock-stretches**; the bus master (`isp_i2c`, VAR/instance variant) honors the stretch with a bounded
guard. The IO cog polls the recognizer in its existing non-blocking round-robin (alongside LED / buzzer
/ ultrasonic), so voice adds no cog.

**Telemetry (producer, latest-wins).** On each recognition the IO cog publishes the **raw DF2301Q
CMDID** as `voiceCmdId` and bumps `voiceCmdSeq` (value-then-seq), exactly mirroring the ranging
producer (`distMm`/`pingSeq`). Readers: `getVoiceCmdId()`, `getVoiceSeq()`, `voicePresent()` (§4.2).
The IO cog does **not** map CMDIDs to behavior or post commands — it stays a pure peripheral server.

**Dispatch loop (consumer).** `robot_dog_top` (cog 0) is the persistent dispatch loop: it watches
`getVoiceSeq()`, and on a fresh CMDID traces it (with its phrase via `isp_voice_command_names.cmdName`),
runs it through the `voiceToDogCmd()` **map seam**, and hands the result to mailbox A — **gated on
motion-completion** from existing backend signals (`getMoveComplete`/`getModeState`/`isBusy`/
`isHalted`): hold mid one-shot, allow a new command to supersede a latched gait, suppress on a
critical-battery halt.

> **Scope — the CMDID→behavior map is now complete (build 0.3.0).** `voiceToDogCmd()` maps the **17
> custom slots 5–21** to the matching `CMD_*` (Stand, Sit, Lie Down, Crouch, Relax, Bow, Forward,
> Backward, Turn L/R, Halt, Say Hi, Shake, Salute, Push Ups, Nod, Parade Rest) plus **built-in aliases
> 22 `Go Forward`→`CMD_FORWARD` and 23 `Retreat`→`CMD_BACKWARD`** (factory words that cover the
> recognizer's near-misses); any other CMDID → `CMD_NONE` (ignored). The 17-word vocabulary was trained
> in **one uninterrupted session** (interrupting corrupts the DF2301Q's sequential slot assignment) and
> cataloged 1:1 by `src/test_voice_map.spin2`. Authoritative map + training order:
> [`../subsystems/VoiceSensor/VOICE-COMMAND-MAP.md`](../subsystems/VoiceSensor/VOICE-COMMAND-MAP.md).
> The harness `src/test_voice.spin2` still proves "do we hear commands over I²C, and which CMDIDs arrive"
> in isolation (IO cog only, dog unpowered-safe). **Open:** the live end-to-end voice→motion bench run.

**Feedback.** The DF2301Q speaks its own verbal acknowledgement (free). The firmware adds a **minimal
green LED blink** on each recognition — the IO cog requests a single-shot green cue from the LED engine
(`isp_led_engine`, 120 ms, reverts to the base mode). The **intended full LED feedback model** is:
**spinning green = acting on a recognized command**, **red = recognized but refused** (e.g. gated/
halted), **off = idle/listening** — the LED engine now makes this easy, but it is **not yet driven from
the dispatch loop** (still open; only the basic green recognition cue is wired).

**Electrical (resolved).** `VOICE_I2C_PULLUP = PU_1K5` (P2 internal strong pull-up), matching the
bench-proven working driver on this hardware (vendor quick-start + `custom_words_example` both call
`start(..., i2c.PU_1K5)`). The module is supplied at **3.3 V** (metered 2026-06-10), so the bus idles
within the P2's range — **no clamp/level-shift needed.** No open bus-2 electrical items. See wiring §3a.

---

## 5. IMU static leveling

A **static** measure → store → apply trim that makes the body stand level at neutral (not a live
closed loop).

- **Measure:** `src/test_dog_level.spin2` (production 3-cog shape, IO cog quiescent) commands the
  calibrated neutral stand, lets it settle, and averages `getAttitude()` over many samples → the
  measured pitch/roll ("how level is it").
- **Store:** the measured pitch/roll are captured into `isp_calibration` (`stancePitchDeg`,
  `stanceRollDeg`) the same way the servo trims were — metered values committed to source.
- **Apply:** `isp_calibration.stanceTrimY(legIdx)` converts the stored tilt into a per-leg foot-Y
  delta using the body lever arms — pitch over the fore/aft half-span (`HALF_BODY_LENGTH_MM = 136`),
  roll over the lateral half-span (`HALF_BODY_WIDTH_MM = 76`), small-angle `ΔY = lever·deg/57`. The
  backend folds these deltas into the neutral stand (`setLevelStandTargets`, used by both the eased
  `standPose` and power-on `seedStand`).
- **Confirm:** re-run `test_dog_level` after storing → residual tilt should be ≈ 0.

**Axis mapping.** The MPU6050 is **mounted rotated 90° in yaw** relative to the textbook X-forward
orientation, so the board's accelerometer **Y axis reads fore/aft** and **X reads lateral**.
`isp_imu.tiltDegrees()` therefore computes **pitch from accel Y** (fore/aft) and **roll from accel X**
(lateral) — `getAttitude()` returns pitch = fore/aft tilt (nose-up positive), roll = left/right tilt.
The fore/aft mapping was **bench-confirmed 2026-06-08** (`test_dog_panel`: a rear-down `SIT` drove
pitch positive, a front-down `BOW` drove it negative, while the lateral channel held the build's
residual). The **lateral (roll) sign is not yet confirmed** — no pure left/right tilt was in that run.

Sign convention (confirm on bench): **+pitch = front high** → lower front, raise back; **+roll =
left high** → lower left, raise right. Both trims default **0**, so the stance is unchanged until
metered.

> ⚠ bench — the IMU **roll (lateral) sign** and the captured trim values are bench-determined; verify
> the roll sign by tilting the body left/right. The fore/aft (pitch) mapping is confirmed; defaults are 0.

---

## 6. Safety floor

Backend-owned (D2), independent of frontend commands. **Two tiers:**

- **Soft advisory — < 6.4 V** (`LOW_BATTERY_CUTOFF_MV`): when the pack reads below the cutoff for
  `LOW_BATT_CONSECUTIVE = 3` consecutive reads (inrush sags are ignored), the backend **eases** to
  RELAX and reports `MODE_LOWBATT`. The forced rest uses the same eased pose path — no snap. The dog
  may still be re-commanded above the hard floor.
- **Hard floor — < 5.0 V** (`CRITICAL_BATTERY_MV`, F8): on **any** read below 5 V the backend runs a
  **confirm-burst** — 3 fresh reads with a wait between (`isCriticalLowConfirmed()`) so a single
  recovering sag does **not** trip it. If all 3 confirm, it logs **`"battery too low"`**, eases to
  RELAX, and **latches a refuse-motion HALT** (`isHalted()` TRUE) — further motion is ignored until
  reset/power-cycle. The orchestrator/panel polls `isHalted()` to **stop the whole run**, not just
  see a refused command. Bench-verified 2026-06-08 (the floor fired on a genuinely flat 4998 mV pack).

---

## 7. Constants reference (build 0.3.0)

| Constant | Value | Meaning |
|---|---|---|
| `FRAME_HZ` | 50 | motion frame rate |
| `EASE_ONE` | 4096 | fixed-point 1.0 for ease/lerp |
| `POSE_FRAMES` / `HEAD_FRAMES` | 30 / 20 | eased pose / head-pan duration |
| `REACH_MIN_MM` / `REACH_MAX_MM` | 25 / 130 | reachability guard |
| `NEUTRAL_FRONT_Y_MM` / `NEUTRAL_REAR_Y_MM` | 95 / 85 | loaded-rear-crouch neutral foot extension (front / deeper-folded rear) — §2.2 |
| `NEUTRAL_FRONT_X_MM` / `NEUTRAL_REAR_X_MM` | 0 / −12 | neutral fore/aft (front under shoulders / rear tucked back → ~60:40 forward bias) — §2.2 |
| `STAND_HEIGHT_MM` | 99 | *tall* stand reference for SIT/BOW/PARADE sub-poses — **no longer the gait/pose neutral** (§2.2) |
| `STANCE_LATERAL_MM` | 10 | foot lateral offset (L +, R −) |
| `RELAX_X_MM` / `RELAX_HEIGHT_MM` | 55 / 78 | tucked rest pose |
| `SIT_FRONT_HEIGHT_MM` | 60 | sit: rear lowered |
| `GAIT_X_AMPL_MM` / `GAIT_LIFT_MM` | 12 / 6 | forward/backward stride / lift |
| `TURN_XZ_AMPL_MM` / `TURN_LIFT_MM` | 3 / 8 | turn fore-aft+lateral / lift |
| `STEP_Z_AMPL_MM` / `STEP_LIFT_MM` | 10 / 5 | sidestep lateral / lift |
| `GAIT_STEP_DEG` | 15 | default gait speed (deg/frame) |
| `GAIT_SPEED_MIN` / `GAIT_SPEED_MAX` | 3 / 45 | gait speed clamp |
| `HALF_BODY_LENGTH_MM` / `HALF_BODY_WIDTH_MM` | 136 / 76 | leveling lever arms |
| `BOW_HEAD_UP_DEG` | 35 | bow head-raise off center (F1); restored to `savedHeadDeg` on `BOW→STAND` (F5) |
| `PAW_LEAN_LAT_MM` | 16 | paw-gesture leaned-sit lateral CoG shift (F4); eased back out on finish (F6) |
| `HELLO_LIFT_MM` | 40 | HELLO wave lift bias so the foot floats off the floor (F7) |
| `LOW_BATTERY_CUTOFF_MV` | 6400 | soft low-battery advisory → ease to RELAX (§6) |
| `CRITICAL_BATTERY_MV` | 5000 | hard floor (F8): confirm-burst → `"battery too low"` + latched HALT (§6) |

---

## 8. Leg kinematics, servo characteristics & limits

Each leg is a **3-link chain** driven by three servos; the head is a single tilt servo. The leg servos
are **unmarked metal-gear micro servos (MG90S-class)**; the head is an **SG90** (plastic gear). **No
datasheet exists for the leg units — every value below was measured on the bench (2026-06-07)** and is
authoritative for these specific servos.

### 8.1 Servo µs ↔ angle

`0–180° = 500–2500 µs`, center `90° = 1500 µs` (matches Freenove `Servo.py`, counts 102/512 @ 50 Hz;
**corrected 2026-06 from a too-narrow 800–2200 µs that reached only ~126°** of travel). **Usable
drivable range ≈ ±80° from center (servo ~10–170°).** Past that the servo just stops responding — a
*pulse edge*, **no mechanical stop, no stall noise**; the gears free-spin further by hand with power off
(~190°/~340°), but that range is blind to the electronics and not commandable.

### 8.2 Leg geometry & axes

| Joint | Link | Length | Axis | Center (90°) | Moves the foot |
|---|---|---|---|---|---|
| Coxa (shoulder) | L1 | 23 mm | horizontal, **fore-aft** (along body) | down-and-out | **lateral ↔ vertical** (in / out / up) |
| Femur (thigh) | L2 | 55 mm | horizontal, **across** (lateral) | straight down | **fore ↔ aft** (stride) + extension |
| Tibia (knee→foot) | L3 | 55 mm | horizontal, **across** (lateral) | foot flat, toes-forward | extension / reach |

The coxa sets the leg's lateral-vertical *plane*; the femur and tibia move the foot fore-aft and in-out
*within* it (`footX` from the femur, `footZ/footY` from the coxa). All-servos-centered = femur vertical
+ foot flat = the natural low-torque "parade rest" pose.

### 8.3 Per-joint drivable clamps (enforced in `isp_leg`)

Both `setJointAngles` and `driveServoDegrees` clamp each joint to its measured drivable range, replacing
the old blanket 0–180°:

| Joint | Servo° clamp | Inward limit set by |
|---|---|---|
| Coxa | **65–170°** | the **body** (leg swings into it) |
| Femur | **10–170°** | none — full servo sweep |
| Tibia | **20–170°** | the **housing** (foot contacts ~15°) |

### 8.4 Calibration

Per-joint mounting offsets are stored as `legTrim` (+ `HEAD_TRIM_DEG`) in `isp_calibration`, applied at
leg init and added inside `setJointAngles`. They are found with the `test_cal_full` Cal tool (dial each
joint, `p` to dump, paste into `isp_calibration`); re-metered 2026-06 under the corrected 500–2500 µs
mapping. The tool starts **centered** (trims = 0) for from-scratch calibration; **`k`** loads the
committed values to dial poses relative to true neutral; **`C`** re-centers.

---

## License

MIT License - See [LICENSE](../../LICENSE) for details.

---

*Part of the Iron Sheep Productions Propeller 2 Projects Collection*

---

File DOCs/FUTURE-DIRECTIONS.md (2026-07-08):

[//]: # (markdownlint-configure-file { "MD013": false, "MD033": false })

# Future Directions — P2 Robot Dog

Detailed companion to the top-level [README](../README.md) "Possible future directions" summary.
These are **candidate** directions for **after** the current port is fully bench-certified —
**none is committed or in progress**, and the current firmware does not depend on any of them. They
are recorded here so the intent — and the hardware/integration thinking behind each — is visible.







> **The common thread.** Every direction below is an **input** that posts into the **cog-0 command
> mailboxes** (`dog.postCommand` / `io.postCommand`) — the exact path the bench move-panel uses. So
> the **motion engine, gait catalog, and gesture set need no change**; each new source just calls
> `postCommand`. A useful consequence: **every `CMD_*` we add now becomes a future *spoken* and
> *remote* command word.**

---

## 1. Speech recognition — *✅ implemented (build 0.3.0)*

**Shipped.** The dog now takes **spoken** commands. A **DFRobot DF2301Q "Gravity" offline voice
recognizer** (`0x64`) was chosen and integrated on a **dedicated 2nd I²C bus** (P18 SCL / P16 SDA), owned
by the IO cog (cog 1). The wake phrase is **"Hello Peabody"**; a 17-word custom vocabulary maps 1:1 to the
dog's `CMD_*` set (plus built-in aliases), dispatched by the cog-0 loop through the motion gate. Full
detail: [`subsystems/VoiceSensor/`](subsystems/VoiceSensor/) and the release notes. Remaining polish: the
live end-to-end bench demo and the full LED feedback scheme.

**How the choice landed vs. the original candidates** (kept for the record). The exploration considered a
UART-*or*-I²C module ([amazon.com/dp/B0C5XG3BXW](https://www.amazon.com/dp/B0C5XG3BXW)) and leaned UART for
a confidence stream. In practice the **I²C DF2301Q** was selected — it does fully-offline recognition with
its own trained vocabulary and reports a latched command-word **ID** (no confidence field), polled from a
result register; it clock-stretches, so it got its own bus rather than joining bus 1. Recognized ID →
`voiceToDogCmd()` → `postCommand` into mailbox A, exactly the "no motion change" integration anticipated.

---

## 2. Pan/tilt head + vision AI camera — *longer-term*

**What.** Replace the current head — a **single, tilt-only servo** (up/down, PCA9685 ch 15; note the
code/docs currently mislabel it "pan") — with a **pan/tilt** mount carrying a **vision AI camera**
that reports *what it sees* (detected objects/scene) back to the controller.

**Hardware candidate.** [amazon.com/dp/B0CX93M5DW](https://www.amazon.com/dp/B0CX93M5DW) — interface
**I²C**.

**P2 integration.**
- The camera runs inference **on-board** and emits **results over I²C** — so there is **no USB-host
  or CSI-ribbon requirement** (the camera-integration risk we worried about is resolved). It joins
  the existing I²C master (P13 SCL / P15 SDA) alongside PCA9685 `0x40` / ADS7830 `0x48` /
  MPU6050 `0x68`; just needs a distinct address and a bus-loading/pull-up check.
- The pan/tilt servos are two more PCA9685 channels (spares today: ch 0, 1, 14 — plus the current
  ch 15 head servo).
- Detections feed **react-to-what-it-sees** behaviors — follow a target, look-at, find/scan — and a
  real **pan** axis restores side-to-side gestures (head-shake "no", lateral scans) that the
  tilt-only head can't do.

**Open questions.** I²C bandwidth/latency for detection results; physical mount; whether pan/tilt
reuses ch 15 + a spare or two fresh channels.

---
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

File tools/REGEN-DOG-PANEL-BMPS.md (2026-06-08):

# Regenerate the Move-Panel BMP assets (host-native)

How to regenerate the five `dog_*.bmp` panel assets from
`tools/gen_dog_panel_assets.py`. **Run this on the host (macOS), not in the
dev container** — the generator renders text with the system fonts
(`Helvetica.ttc` / `Arial.ttf` / `SFNS.ttf`); if those are missing it silently
falls back to an ugly bitmap default font. The container has no Pillow and no
those fonts, so the committed BMPs are always Mac-generated.

You are running host-native, so you can run these tools directly.

## What gets written

The script writes **5 files into `src/`** (it computes `OUT = ../src`):
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

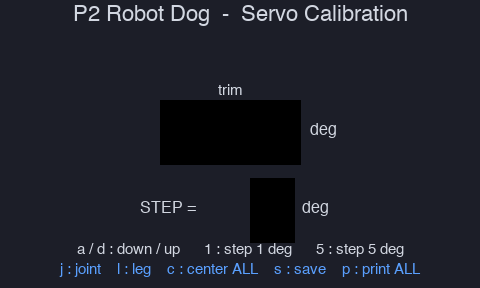
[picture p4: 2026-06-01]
src/panel_bg.bmp

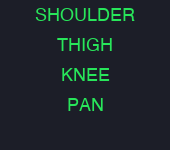
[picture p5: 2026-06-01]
src/panel_joints.bmp

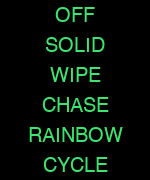
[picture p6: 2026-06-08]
src/dog_led_modes.bmp

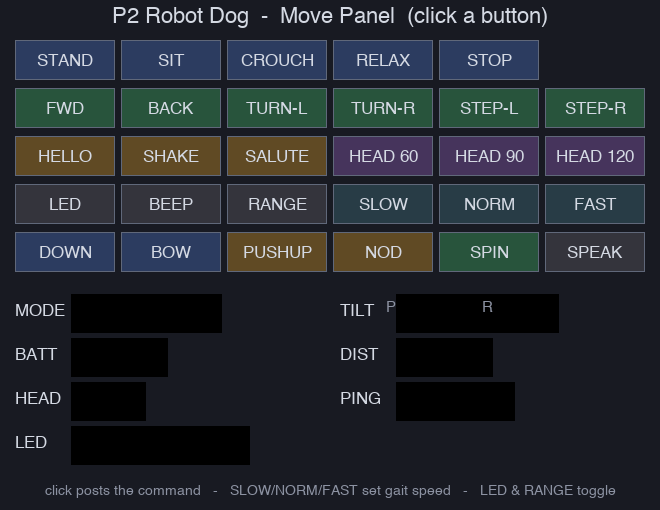
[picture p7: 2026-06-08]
src/dog_panel_bg.bmp

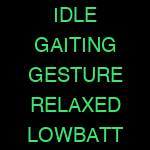
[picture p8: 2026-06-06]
src/dog_modes.bmp

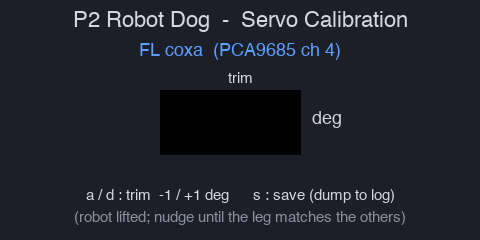
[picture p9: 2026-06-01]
src/cal_bg.bmp

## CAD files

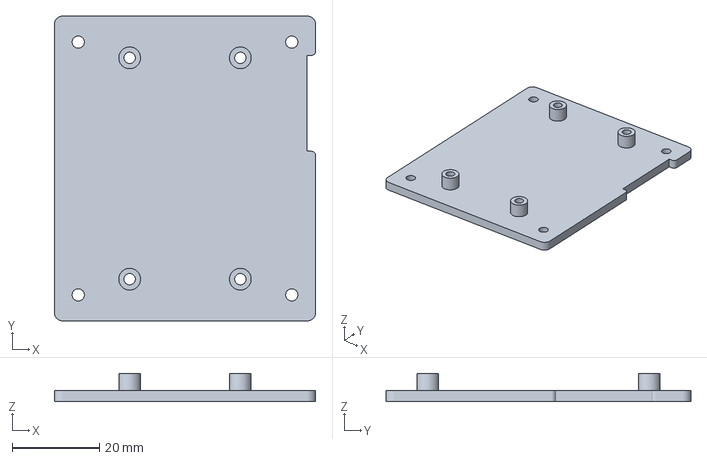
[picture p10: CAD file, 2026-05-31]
DOCs/P2-platform/RoboDogP2PlateV2.3mf
60.0 x 70.0 x 6.50 mm

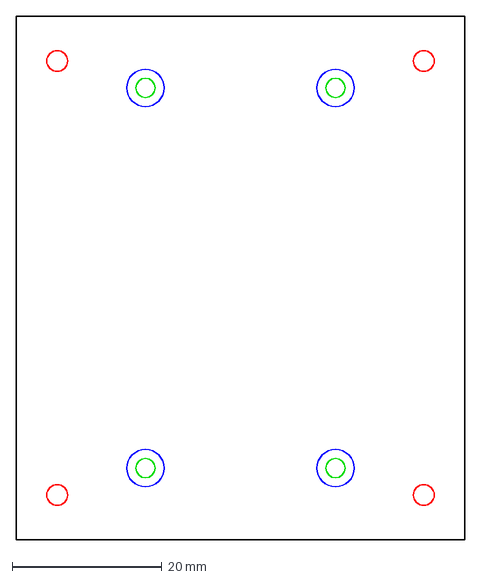
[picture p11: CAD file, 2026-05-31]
DOCs/P2-platform/pi_p2_mount_plate.dxf
60.0 x 70.0 mm

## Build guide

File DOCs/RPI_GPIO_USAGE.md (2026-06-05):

# Raspberry Pi GPIO / Pin Usage







Reverse-engineered from the server source (`Code/Server/`). **No schematic exists** for
this kit in the repo — every pin below was traced from the code that drives it, with the
file/line cited. All GPIO numbers are **BCM** (Broadcom) numbering, which is what both
`gpiozero` and `rpi_ws281x` use by default. Official kit docs: **Freenove FNK0050** —
https://docs.freenove.com/projects/fnk0050/en/latest/ . For the P2 swap (power, charging,
wiring map) see [`P2_MIGRATION_WIRING.md`](P2-platform/P2_MIGRATION_WIRING.md).

> **This build uses PCB v1.0.** On the v1.0 connection board the WS2812 LED data line is
> **GPIO18 (PWM0)** via the `rpi_ws281x` driver — *not* the SPI0/GPIO10 path used by PCB
> v2.0. (Reminder: PCB v1.0 + Raspberry Pi 5 is **unsupported** for the LEDs; v1.0 targets
> Pi 1–4.) Everything else below is identical across PCB versions.

> **Key takeaway:** very little hangs off raw GPIO. The 13 servos, the battery ADC, and
> the IMU are all on the **I²C bus**, reached through dedicated driver chips. Only the
> buzzer, the ultrasonic sensor, and the WS2812 LED data line use discrete GPIO pins —
> and the LED pin *changes with PCB/Pi version*.

## Device inventory — what's accessed, how, and why

Every peripheral the server touches, and the bus it rides. Note the **"On raw GPIO?"**
column: only the buzzer and the ultrasonic ("ping") sensor — plus the LED data line — talk
to the Pi over discrete GPIO. The remaining sensors/actuators are on I²C behind driver
chips, so they consume **no** dedicated GPIO beyond the shared SDA/SCL pair.

| Device | Type | Access path | On raw GPIO? | Purpose in the robot | Source |
|---|---|---|---|---|---|
| **HC‑SR04 ultrasonic** ("ping") | Sensor (input) | TRIG=GPIO27, ECHO=GPIO22 | **Yes** | Forward obstacle / distance ranging; reported on `CMD_SONIC` | `Ultrasonic.py` |
| **MPU6050 IMU** | Sensor (input) | I²C `0x68` | No (I²C) | 6-axis accel+gyro for self-balancing and body attitude (roll/pitch/yaw); feeds Kalman + PID | `IMU.py`, `Control.py` |
| **ADS7830 ADC** | Sensor (input) | I²C `0x48` | No (I²C) | Battery-voltage monitoring (ch 0); low-battery auto-shutdown < 6.4 V | `ADS7830.py`, `Server.py` |
| **Pi Camera** | Sensor (input) | CSI ribbon | No (CSI) | Live video stream to client (port 8001); face/ball tracking on client side | `Server.py`, `camera.py` |
| **PCA9685 → 13× servos** | Actuator (output) | I²C `0x40` → PWM ch 2–13, 15 | No (I²C) | 12 leg-joint servos (gait/IK) + 1 head-pan servo | `Servo.py`, `Control.py`, `Action.py` |
| **Passive buzzer** | Actuator (output) | GPIO17 | **Yes** | Audible alert / horn (`CMD_BUZZER`) | `Buzzer.py` |
| **WS2812 RGB strip (7 px)** | Actuator (output) | GPIO18 *or* SPI0‑MOSI GPIO10 | **Yes** (data line) | Status / decorative lighting effects (`CMD_LED`, `CMD_LED_MOD`) | `Led.py`, `rpi_ledpixel.py`, `spi_ledpixel.py` |

**Direct answer on the ping sensor:** yes — the HC‑SR04 ultrasonic is the one *sensor*
wired to raw Raspberry Pi GPIO (TRIG on GPIO27, ECHO on GPIO22, via `gpiozero`). It is the
robot's only distance/proximity sensor and its only GPIO **input**. Every other sensor
(IMU, battery ADC, camera) reaches the Pi over a bus (I²C or CSI), not discrete GPIO.

## Summary table

| BCM GPIO | Hdr pin | Direction | Signal / function | Attached device | Source |
|---|---|---|---|---|---|
| GPIO2 (SDA1) | 3 | bidir | **I²C data** — servos, ADC, IMU | PCA9685, ADS7830, MPU6050 | `PCA9685.py:29`, `ADS7830.py:6`, `IMU.py:24` |
| GPIO3 (SCL1) | 5 | out | **I²C clock** — same bus | same as above | same |
| GPIO17 | 11 | out | **Buzzer** drive (on/off) | passive/active buzzer | `Buzzer.py:3` |
| GPIO27 | 13 | out | **Ultrasonic TRIG** | HC‑SR04 | `Ultrasonic.py:8` |
| GPIO22 | 15 | in | **Ultrasonic ECHO** | HC‑SR04 | `Ultrasonic.py:9` |
| GPIO18 (PWM0) | 12 | out | **WS2812 LED data** — *PCB v1 + Pi ≤4 only* | RGB LED strip (7 px) | `rpi_ledpixel.py:23` |
| GPIO10 (SPI0 MOSI) | 19 | out | **WS2812 LED data** — *PCB v2 (all Pi)* | RGB LED strip (7 px) | `spi_ledpixel.py` + `Led.py:22` |
| GPIO9 / 11 / 8 | 21 / 23 / 24 | — | SPI0 MISO / SCLK / CE0 — *reserved when SPI is enabled, not actively used* | — | SPI0 bus |
| CSI camera connector | (ribbon) | — | Camera video (not on the 40‑pin header) | Pi Camera | `Server.py`, `camera.py` |

GPIO numbers **not** used by this code: everything else on the header is free as far as
the software is concerned (GPIO0, 1, 4–7, 12–16, 19–26 — note the SPI0 secondaries above
are only occupied if SPI is enabled for the v2 LED path).

---

## 1. I²C bus (GPIO2 = SDA1, GPIO3 = SCL1)

All driver chips share I²C bus **1** (`smbus.SMBus(1)`). Three devices live here:

| Device | I²C addr | Role | Source |
|---|---|---|---|
| **PCA9685** | `0x40` | 16-channel PWM generator → drives all servos | `PCA9685.py:28`, `Servo.py:7` |
| **ADS7830** | `0x48` | 8-channel ADC → reads battery voltage (ch 0) | `ADS7830.py:8` |
| **MPU6050** | `0x68` | 6-axis IMU (accel + gyro) for balance/attitude | `IMU.py:24` |

`config.txt` enables this bus with `dtparam=i2c_arm=on`.

### Servo channel map (PCA9685, **PWM channels — not Pi GPIO**)
The PCA9685 outputs PWM on its own 16 channels @ 50 Hz; angle 0–180° maps to count 102–512
(`Servo.py`). 13 of the 16 channels are used:

| PCA9685 ch | Function | Source |
|---|---|---|
| 2, 3, 4 | Leg 0 (front-left): lower, middle, hip | `Control.py:112-114` (i=0) |
| 5, 6, 7 | Leg 1 (front-right): lower, middle, hip | `Control.py:112-114` (i=1) |
| 8, 9, 10 | Leg 2 (rear-left): hip, middle, lower | `Control.py:115-117` (i=0) |
| 11, 12, 13 | Leg 3 (rear-right): hip, middle, lower | `Control.py:115-117` (i=1) |
| 15 | **Head pan** servo | `Server.py` (`CMD_HEAD`), `Action.py:8` |
| 0, 1, 14 | unused | — |

(Each leg = 3 joints; the gait engine writes all 12 leg channels per `run()` step. The
head is driven directly by `CMD_HEAD#<angle>`.)

### Battery sense (ADS7830 channel 0)
`adc.power(0)` reads ADC channel 0 and scales `data/255 * 5.0 * 2` — the `× 2` implies a
half-scale resistor divider on the pack voltage. Server shuts the dog down below 6.4 V
(`Server.battery_reminder`).

---

## 2. Buzzer — GPIO17 (header pin 11)

`gpiozero.Buzzer(17)`, simple on/off (`Buzzer.py`). Triggered by `CMD_BUZZER#1` / `#0`.
Note: `config.txt` has commented-out IR overlays that *would* also claim GPIO17
(`dtoverlay=gpio-ir,gpio_pin=17`) — they are disabled, so no conflict, but worth knowing.

## 3. Ultrasonic distance — TRIG GPIO27 (pin 13), ECHO GPIO22 (pin 15)

`gpiozero.DistanceSensor(echo=22, trigger=27, max_distance=3)` (`Ultrasonic.py`). HC‑SR04
style sensor; `get_distance()` returns cm. Served on demand via `CMD_SONIC`. ECHO is the
only **input** GPIO in the design — on a real HC‑SR04 its 5 V echo needs a divider to the
Pi's 3.3 V input (assume present on the PCB).

## 4. WS2812 RGB LEDs — pin depends on PCB **and** Pi version

`Led.py` picks the driver from `params.json` (set by `parameter.py`). Both paths drive a
**7-pixel** strip, but over different hardware:

| PCB | Pi | Driver | Data pin | Notes |
|---|---|---|---|---|
| v1.0 | Pi 1–4 | `Freenove_RPI_WS281X` (rpi_ws281x) | **GPIO18** (PWM0) | `Adafruit_NeoPixel(7, 18, 800000, 10, …)` → pin 18, DMA 10, ch 0 (`rpi_ledpixel.py:23`) |
| v2.0 | Pi 1–5 | `Freenove_SPI_LedPixel` (spidev) | **GPIO10** (SPI0 MOSI) | Bit-bangs WS2812 timing over SPI MOSI; needs SPI enabled (`spi_ledpixel.py`) |
| v1.0 | Pi 5 | — | — | **Unsupported**; LEDs disabled (`Led.py:24`) |

For the v2/SPI path the WS2812 data rides **GPIO10 (MOSI)** only; SPI0's MISO (GPIO9),
SCLK (GPIO11) and CE0 (GPIO8) are reserved by the enabled SPI peripheral but not
functionally used for the LEDs. SPI must be turned on (`dtparam=spi=on` / `raspi-config`);
the driver prints setup hints if `/dev/spidev*` is missing.

## 5. Camera — CSI connector (not a GPIO)

`Server.py` / `camera.py` use `picamera2`; the camera attaches via the dedicated CSI
ribbon connector, not the 40-pin GPIO header. `Code/Patch/` patches `libmmal.so` for the
legacy stack on Bullseye.

---

## Caveats

- Pins were traced from code only; without a schematic, **level-shifting, pull resistors,
  power rails, and the exact 5 V/3.3 V routing on the connection PCB are unconfirmed.** The
  ADS7830 `×2` divider and the HC‑SR04 echo divider are inferred, not verified.
- Header pin numbers assume the standard 40-pin Raspberry Pi GPIO header.
- The version-dependent LED pin (GPIO18 vs GPIO10) is the single biggest gotcha for any
  port: read `params.json` before assuming which line carries LED data.

---

## License

MIT License - See [LICENSE](../LICENSE) for details.

---

*Part of the Iron Sheep Productions Propeller 2 Projects Collection*

---

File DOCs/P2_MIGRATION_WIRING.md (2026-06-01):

# P2 Migration — Power & Wiring Map (replacing the Raspberry Pi)







Goal: drop a **Propeller 2 Edge Module + experiment/breakout board** in where the
Raspberry Pi sits, via an adapter that mates to the connection board's 40-pin header.

**Hardware on this build: PCB v1.0** (so the WS2812 LED data line is on **GPIO18**, the
`rpi_ws281x` path — see [`RPI_GPIO_USAGE.md`](RPI_GPIO_USAGE.md)).

> ⚠️ **Confidence levels.** *Signal* assignments are **code-derived** (certain — traced in
> the server source). Power *direction* is **confirmed by Freenove's docs** (§1).
> **Bench-measured 2026-05-31** (Pi removed, P2 adapter not yet fitted): **5 V rail present**
> (pins 2/4); **grounds common** (6/9/14 at 0 V); **3.3 V rail absent** (#1 gotcha confirmed),
> pins 1/17 sitting at **~5 V**; and **no I²C pull-ups on the board** — SDA/SCL are open to both
> rails (the Pi's own ~1.8 kΩ pull-ups left with it). So the **P2 must supply 3.3 V pull-ups**
> and there is **no 5 V-idled-bus hazard** (§2, §4). The 3.3 V/5 V rails are **not bridged**
> (30+ MΩ) so the 5 V on pins 1/17 is benign leakage and the **MPU6050 (VDD max 3.46 V) is
> safe**. ~~Remaining: classify the SDA→GND 6.9 kΩ path and check the ECHO divider.~~
> **✅ All resolved — bring-up 2026-06-01 (P2 fitted, battery in):** the SDA→GND path is a real
> 6.9 kΩ resistor (use `PU_1K5`), ECHO is 5 V undivided (now read via a fitted ~1 kΩ series R into
> P9), and with the adapter's 3.3 V rail + P2 `PU_1K5` pull-ups **all three I²C devices answer**
> (0x40/0x48/0x68). Per-interface results: §7.

### Additional resources
- **Freenove FNK0050 official docs (Robot Dog):** https://docs.freenove.com/projects/fnk0050/en/latest/
  - Assembly + power switches: https://docs.freenove.com/projects/fnk0050/en/latest/fnk0050/codes/tutorial/2_Assemble_Robot.html
- **Battery info** (also in repo: `About_Battery.pdf`): the kit uses **2× 18650 Li-ion** cells.
  Battery list / purchase: https://github.com/Freenove/Freenove_Battery_List
- Companion docs in this repo: [`RPI_GPIO_USAGE.md`](RPI_GPIO_USAGE.md), [`CLAUDE.md`](CLAUDE.md).

---

## 1. Direct answers

**Who powers whom?** The **robot powers the controller**, not the other way around —
**confirmed by Freenove's docs**: *"If you disconnect cable, the batteries will power
Raspberry Pi"* and *"all servos connect to the shield for power."* The battery pack feeds a
regulator on the connection board (shield), which delivers **5 V into the Pi's 40-pin
header** (pins 2 & 4). The Pi never powered the servos — 13 servos pull amps, far beyond
what a controller can source.

**Two power switches** (from the assembly docs): pressing **S1 and S2** lights two
indicators. **S1 = "Load"** gates the **servo** power rail (the docs have you toggle Load
off to install screws so the servos aren't energized); the other switch gates main/logic
(Pi) power. ➜ For P2 bring-up this is a gift: you can power the **P2 + logic with the Load
switch OFF** to test the **I²C devices** (servo controller, ADC, IMU) and code with the legs
de-powered, then enable servos. **Exception (measured 2026-05-31): the ultrasonic is on the
Load/servo rail** — it's only live with Load ON, so it can't be brought up in the legs-off mode;
support the robot when testing it.

**USB caveat:** a USB cable can power the Pi *in parallel* with the battery (*"you can still
use cable to power Raspberry Pi with switches ON"*) — but **USB does not charge the
batteries** (see Battery & charging below).

**What voltage is on the connector?**
- **5 V** — sourced *by the robot* (battery → board buck regulator), present on header
  **pins 2 & 4**. This is your input power for the P2 board.
- **3.3 V** — on header **pins 1 & 17**, but historically **generated by the Pi** and
  handed *out* to the connection board's logic/I²C pull-ups. **Remove the Pi and this rail
  vanishes** — your P2 adapter must *supply* 3.3 V back onto these pins if the board's I²C
  chips/pull-ups depend on it (very likely). This is the #1 gotcha.
  **Bench-confirmed 2026-05-31:** with the Pi removed, pins 1/17 are **not** at 3.3 V — they
  measure **~5 V** against grounds 6/9/14. The 5 V (vs floating) hints the rail may be
  resistively pulled toward 5 V; the §2 resistance test will say through what. The adapter
  must drive a real 3.3 V here.
- Battery voltage (7.4 V nom / 8.4 V full / 6.4 V cutoff — from `ADS7830.py`,
  `Server.battery_reminder`) stays on the board's servo/sensor rails; it is **not** exposed
  on the 40-pin header.

**5 V or 3.3 V for the P2?** The P2 is a **3.3 V part and its I/O is NOT 5 V tolerant**
(pin abs-max ≈ 3.6 V). You feed the P2 board **5 V** (it regulates to 3.3 V on-board), and
every *signal* line into a P2 pin must be ≤ 3.3 V. The good news: the Pi was also 3.3 V, so
the board was already built for 3.3 V logic — but the two 5 V-native sensors (ultrasonic,
WS2812) are the ones to watch (§4).

---

## 1b. Battery & charging — getting the device ready for use

Sourced from `About_Battery.pdf` (in this repo) + the FNK0050 docs + the software's own
voltage thresholds.

- **Cells:** **2× 18650 Li-ion**, **unprotected**, flat-top *or* button-top. **Not
  included** — buy separately (Freenove battery list above). Wired **2-series (2S)**.
- **Voltage (from `ADS7830.py` / `Server.py`):** **8.4 V** full (2 × 4.2 V), **7.4 V**
  nominal, software **low-battery cutoff at 6.4 V** → at/below that the server relaxes the
  legs and exits. The ADC reads the pack through a **÷3 divider** — **METERED 2026-06-01**:
  a 7.68 V pack reads raw **131** (≈ 2.57 V at the ADC pin), so pin = pack/3, **not** the
  `×2` in Freenove's `ADS7830.py` (`data/255 × 5.0 × 2`), which is wrong for this v1.0 board.
  `isp_battery_monitor` now uses `DIVIDER_RATIO = 3`; bring-up reads **7.76 V vs 7.68 V
  metered** (±1 LSB ≈ 59 mV through the divider).
- **⚠️ No on-board charging.** Direct quote: *"The control board connected to the USB cable
  will **not** charge the batteries. So you also need a charger."* You **remove the 18650
  cells and charge them in an external 18650 charger** (*"almost any charger suitable for
  18650 batteries can be used"*), then reinstall. There is **no charge port, no charge IC,
  and no in-place charging** on this board.
- **Readiness checklist before powering the robot:**
  - [ ] Charge both 18650s **fully (~4.2 V each / 8.4 V pack)** in an external charger.
  - [ ] Observe **polarity** — *"Don't reverse batteries. Or the board will be damaged."*
  - [ ] Insert cells **before** running servos (*"prepare the right batteries and fully
        charge them before assembling … without right batteries will … damage the servos"*).
  - [ ] Use a matched pair (same brand/capacity/charge state) for a 2S pack.
- **Implication for the P2 port:** the power-readiness story is **unchanged** by swapping in
  the P2 — you still hand-charge 18650s externally and the battery still feeds the shield's
  5 V regulator. The P2 board simply replaces the Pi as the 5 V load. If you want true
  in-place / USB charging you'd have to **add** a 2S charge circuit (e.g. a BMS/charger
  module) yourself; the kit has none.

## 2. Power architecture (rails inferred — verify each arrow)

```
  2S Li-ion pack ──► Board buck reg ──► 5V rail ─┬─► header pins 2,4  ──► (was) Pi 5V in
   7.4–8.4V         (on conn. board)             ├─► servo V+ (PCA9685 power)
                                                 ├─► HC-SR04 Vcc (5V)
                                                 └─► WS2812 Vcc (5V)

  Pi onboard 3.3V reg ──► header pins 1,17 ──► board I²C pull-ups + PCA9685/ADS7830/MPU6050 Vcc(logic?)
       (DISAPPEARS when the Pi is removed — P2 board must replace this source)
```

**Verify with a multimeter (Pi removed, battery off unless noted):**
1. **5 V rail** — power the board, measure header pin 2/4 → GND. Expect ~5 V. Confirm the
   regulator is rated for the P2's draw (P2 ≈ 0.1–0.4 A; trivially less than the Pi it
   replaced, so almost certainly fine).
2. **3.3 V provenance** — continuity/resistance from the I²C chips' Vcc and the SDA/SCL
   pull-up resistors to header **pins 1/17** vs. to the **5 V** rail. This tells you whether
   those chips run on 3.3 V (you must re-supply it) or on 5 V (then their I²C is pulled to
   5 V → you need level shifting — see §4).
3. **I²C pull-up rail** — measure SDA (pin 3) and SCL (pin 5) idle voltage with the board
   powered and a known-good 3.3 V applied to pins 1/17. Must idle at ~3.3 V, not 5 V.
4. **HC-SR04 ECHO divider** — check for a resistor divider on ECHO (pin 15) between the
   sensor and the header. If raw 5 V reaches the header pin, **do not** connect it to the
   P2 without adding one (§4).

### Bench measurements — 2026-05-31 (Pi removed, P2 adapter not yet fitted)

> **Protocol:** resistance/continuity readings are taken with the **batteries OUT** (fully
> de-energized) — required for valid ohmmeter readings. **Finding:** with the cells **in**, the
> board is partially energized **even with both switches OFF** (readings shift), so the pack
> feeds an **always-on path** (regulator input hard-wired to the battery and/or a standby /
> battery-sense rail). ⇒ expect **parasitic standby drain** — pull the 18650s for storage, or
> quantify the standby current. Voltage readings are taken batteries-in with the noted switch.

| Check | Result | Status |
|---|---|---|
| **5 V rail** (pins 2/4 → GND) | **~5 V present** | ✅ measured |
| **Grounds** (pins 6, 9, 14) | all **0 V** to each other (to the 3rd digit) → common ground | ✅ measured |
| **3.3 V rail** (pins 1/17 → GND) | **not 3.3 V — reads ~5 V** vs grounds 6/9/14 (no 3.3 V anywhere on the header) | ⚠️ #1 gotcha confirmed; rail absent |
| **I²C pull-ups** (unpowered Ω) | SDA(3)/SCL(5) → 3.3 V (1/17): **open** (≤ 0.8 MΩ); → 5 V (2/4): **8.8 MΩ** (both lines, both 5 V pins) | ✅ measured — **no board pull-ups on either rail** |
| **Rails bridged?** (pin 1 ↔ pin 2) | **30–33 MΩ** | ✅ measured — **not bridged** (5 V on 1/17 is leakage only) |
| **SDA / SCL → GND** (unpowered Ω) | SDA: **6.9 kΩ** (same both probe polarities) · SCL: **6.3 MΩ** | ✅ measured — **real ~6.9 kΩ pull-down on SDA** (not a diode) → use `PU_1K5` |
| **ECHO @ header** (pin 15 → GND) | **15.5 MΩ** — no divider lower-leg | ✅ measured — board does NOT divide ECHO |
| **HC-SR04 VCC / power** | **5 V**, on the 4-wire sensor cable; live **only with the Load/servo switch ON** | ✅ measured — ECHO = **5 V** ⇒ **~1 kΩ series R on P9**; ultrasonic not on logic power |

> **✅ Pull-up rail & 5 V hazard — RESOLVED.** No board pull-ups on SDA/SCL — the Raspberry
> Pi's own ~1.8 kΩ I²C-1 pull-ups to 3.3 V left **with the Pi** — and the 3.3 V/5 V rails are
> **not bridged** (30+ MΩ), so the 5 V on pins 1/17 is harmless leakage and the **MPU6050
> (VDD max 3.46 V) is not at risk**. There is **no 5 V-idled-bus hazard.** Action: the **P2
> supplies the I²C pull-ups to 3.3 V** (`isp_i2c_singleton` `PU_3K3`/`PU_1K5`, or external) and
> drives a real 3.3 V onto pins 1/17 — trivially overpowering the 30 MΩ leakage.
>
> **✅ SDA → GND = 6.9 kΩ — RESOLVED.** Same resistance in **both probe polarities** ⇒ a **real
> ~6.9 kΩ resistor (a pull-down on SDA)**, not an ESD diode; SCL has none (6.3 MΩ). It loads the
> bus high level, so **use the P2's strongest internal pull-up, `PU_1K5`** → SDA idles
> 3.3 × 6.9/(1.5 + 6.9) ≈ **2.71 V** (valid high; VIH ≈ 2.31 V). **Avoid `PU_3K3`** (≈ 2.2 V →
> fails). Add an external ~1 kΩ pull-up to 3.3 V for more margin if wanted. **Confirm SDA idles
> ≈ 2.7 V once powered.** The asymmetric pull-down's origin is unknown (no schematic) — worth
> understanding later; it does not block bring-up.

---

## 3. Wiring map: connection-board header → P2

Signal columns are **certain** (from code). The **P2-pin column is the as-built adapter map,
verified on hardware 2026-05-31**: base **P8**, with offsets **LED +0, ECHO +1, Buzzer +2,
TRIG +3, SCL +5, SDA +7** (P12 and P14 left spare). Rows are in P2-pin order.

| P2 pin | Robo hdr | BCM | Function (certain) | Notes |
|---|---|---|---|---|
| **P8** | 12 | GPIO18 | **WS2812 LED data** (PCB v1.0) | 3.3 V data into 5 V strip (§4) |
| **P9** | 15 | GPIO22 | **Ultrasonic ECHO** (input) | 5 V undivided → **~1 kΩ inline series R** + P2 clamp (§4); sensor live only with Load switch ON |
| **P10** | 11 | GPIO17 | **Buzzer** drive | P2 output; safe |
| **P11** | 13 | GPIO27 | **Ultrasonic TRIG** | P2 output (3.3 V triggers HC-SR04 fine) |
| **P12** | — | — | *spare* | unassigned |
| **P13** | 5 | GPIO3 | **I²C SCL** | 3.3 V open-drain; **P2 supplies pull-up (`PU_1K5`)** |
| **P14** | — | — | *spare* | unassigned |
| **P15** | 3 | GPIO2 | **I²C SDA** → PCA9685 (servos), ADS7830 (battery), MPU6050 (IMU) | **6.9 kΩ board pull-down → `PU_1K5`** |
| — | 2, 4 | 5V | **Power IN from robot** → P2 board 5 V input | sized for the regulator (verify) |
| — | 1, 17 | 3.3V | **3.3 V** ← from P2 board 3.3 V out | feed *back* to board; chips' VDD + bus reference |
| — | 6,9,14,… | GND | Ground → **common GND** | tie robot GND ↔ P2 GND |

> Map is **as-built and verified on hardware** (2026-05-31) — not a proposal. ECHO carries a
> ~1 kΩ inline series resistor into P9 (5 V; P2 clamp). P12 and P14 are the spares.

**P2 Edge reserved pins — don't use for robot I/O:** the Edge module uses **P58–P61** for
the boot SPI flash and **P62/P63** for the serial/programming host. The **P8–P15** block
chosen above sits safely inside the usable **P0–P57** range. The experiment/breakout board
supplies the module's 3.3 V from a 5 V input — that's the regulator you feed from the
robot's 5 V and tap to re-supply header pins 1/17.

---

## 4. 3.3 V vs 5 V — over-voltage handling (P2 pins clamp to VIO, ≤ ±10 mA)

| Line | Direction | Risk | Action |
|---|---|---|---|
| **I²C SDA/SCL** | bidir | **No board pull-ups** (open to both rails); **SDA has a real ~6.9 kΩ pull-down to GND** (2026-05-31, §2). Bus is 3.3 V — no 5 V hazard | **P2 supplies the pull-ups** — use the strongest internal mode **`PU_1K5`** so SDA idles ~2.71 V over the pull-down (valid high; **`PU_3K3` ≈ 2.2 V → fails**). **Applied:** `isp_i2c_ads7830` / `isp_i2c_mpu6050` / the bring-up console set `PU_1K5`; the seed `isp_i2c_pca9685`'s `PU_NONE` is overridden to `PU_1K5` via a **Spin2 OBJ CON override** at the call site (no seed edit). Optional external ~1 kΩ to 3.3 V for margin. |
| **Ultrasonic ECHO** | sensor→P2 | HC-SR04 echo = **5 V** (VCC measured 5 V, undivided) | **Fit a ~1 kΩ series R into P9** — the P2 pin clamps the 5 V to VIO (≤ 10 mA). Ultrasonic is powered only with the **Load/servo switch ON** (4-wire cable: GND/VCC/ECHO/TRIG) |
| **Ultrasonic TRIG** | P2→sensor | P2 drives 3.3 V; HC-SR04 trigger threshold usually OK | Safe; if flaky, level-shift up to 5 V |
| **Buzzer** | P2→board | Driving a transistor/driver from 3.3 V | Safe (output) |
| **WS2812 data** | P2→strip | 3.3 V data into a 5 V strip (data-high threshold ≈ 0.7·Vcc) | The Pi did this at 3.3 V already; usually works. If the first pixel is unreliable, add a 3.3→5 V level shifter (74AHCT125) or power the strip at ~4.3 V |

P2 pins have **configurable drive strength / pull-ups / pull-downs** (P_HIGH_FLOAT / 1K5 /
15K / ~1 mA modes via the WRPIN M-field); set adequate drive for TRIG, buzzer, and the LED
data line, and use the internal pull-ups to source the (absent) I²C bus pull-ups to 3.3 V.

**P2 over-voltage clamp (datasheet).** Each P2 I/O pin has an internal **clamp diode to VIO**
(≈ 3.3 V); the abs-max "VIO + 0.3 V" is that diode's forward drop. The datasheet **explicitly
permits over-voltage** as long as the clamp's forward current stays **≤ ±10 mA**. So a P2 pin
safely *reads* a higher-voltage signal through a current-limiting series resistor:
R ≥ (Vin − 3.6 V) / 10 mA → for 5 V, R ≥ ~140 Ω; use **~1 kΩ** (≈ 1.4 mA) for margin. The clamp
current flows into VIO (trivial vs the P2's draw; raise R if that rail is ever lightly loaded).
*Caveats:* a **bare** pin must still stay ≤ VIO + 0.3 V, and the P2 cannot **drive** 5 V — the
series resistor is what makes reading 5 V safe. **The Raspberry Pi's GPIO, by contrast, is 3.3 V
and NOT 5 V-tolerant with no such clamp headroom** — which is itself a useful clue (next).

**ECHO is 5 V — RESOLVED (measured 2026-05-31).** pin 15 → GND = **15.5 MΩ** (no divider
lower-leg on the ECHO net) **and** the **HC-SR04 VCC = 5 V**, measured on the **4-wire sensor
cable** (GND/VCC/ECHO/TRIG — a direct passthrough to the daughterboard, no in-line divider). So
ECHO reaches header pin 15 as an **undivided 5 V** push-pull pulse. The
original Pi evidently tolerated this without a divider (not recommended); the **P2 does it
correctly with a ~1 kΩ series resistor into P9** — the pin clamps the 5 V to VIO with the
resistor holding clamp current to ~1.4 mA (≤ 10 mA).

**Power domain:** the ultrasonic is powered **only when the Load/servo switch is ON** — it is
*not* on the logic rail, so it can't be exercised in the legs-de-powered "safe" mode. Bring it
up with **Load on and the robot supported**.

---

## 5. What stays the same on the firmware side

Most of the robot is on **I²C**, so porting is mostly "implement an I²C master on the P2":
- **Servos** (PCA9685 @ `0x40`), **battery ADC** (ADS7830 @ `0x48`), **IMU** (MPU6050 @
  `0x68`) — all spoken to over the *same* I²C bus the Pi used. The P2 just needs an I²C
  master (smart-pin or bit-banged; OBEX has I²C objects). Register sequences, the 50 Hz
  servo timing, and the channel→leg map are documented in `CLAUDE.md` / `RPI_GPIO_USAGE.md`
  and translate 1:1.
- Only the **3 raw-GPIO devices** (buzzer, ultrasonic, WS2812) need P2-native pin code —
  the buzzer is trivial, the ultrasonic is a TRIG pulse + ECHO timing (a natural fit for a
  P2 smart pin in pulse-measure mode), and the WS2812 is a classic P2 smart-pin/streamer task.

---

## 6. Pre-wiring checklist

- [x] Meter the **5 V** rail on header pins 2/4 — **~5 V present (2026-05-31)**; still confirm the board regulator's current headroom.
- [~] Determine **3.3 V provenance** (pins 1/17) — **measured ~5 V, not 3.3 V (2026-05-31)**; rail is absent and pulled toward 5 V. Run the resistance test to find through what.
- [x] Confirm **I²C pull-up rail** is 3.3 V (not 5 V) — **RESOLVED (bring-up 2026-06-01)**: adapter
      supplies 3.3 V on 1/17, P2 drives `PU_1K5`, and all three I²C devices ACK (0x40/0x48/0x68).
- [x] **ECHO is 5 V, undivided** (pin 15→GND 15.5 MΩ; VCC 5 V, 2026-05-31) → **~1 kΩ series R into
      P9 fitted; ranging PASS 2026-06-01** (P2 pin clamp, ≤10 mA). Ultrasonic on the **Load/servo
      rail** — only live with Load ON.
- [~] Establish a single **common ground** — robot grounds (pins 6/9/14) **verified consistent at 0 V (2026-05-31)**; still tie robot GND ↔ P2 GND at wiring.
- [ ] Keep robot signals on **P0–P57**; leave **P58–P63** for flash/serial.

---

## 7. Bring-up verification (2026-06-01)

P2 fitted on the adapter, battery installed. Each interface proven in isolation with a dedicated
`src/test_*.spin2` top file emitting P2 `DEBUG()` at 2 Mbaud (see `P2_BRINGUP_PLAYBOOK.md` for the
method and `src/README.md` §7 for the run recipe). Discrete-pin and bus facts confirmed:

| Interface | Pins | Result | Note |
|---|---|---|---|
| I²C bus | SCL P13 / SDA P15 | ✅ PASS | 0x40 PCA9685, 0x48 ADS7830, 0x68 MPU6050 (+0x70 = PCA9685 all-call). 3.3 V rail + `PU_1K5` confirmed. |
| WS2812 LED ring | P8 | ✅ PASS | Solid R/G/B (GRB order correct) + rainbow, all 7 px; 3.3 V data into 5 V strip works. |
| Buzzer | P10 | ✅ PASS | **Only sounds with the Load/servo switch ON** — the buzzer is on the Load rail, not logic power. |
| Ultrasonic | TRIG P11 / ECHO P9 | ✅ PASS | Tracks distance; **~1 kΩ inline series R into P9** handles the 5 V echo via the pin clamp. Load on. |
| IMU (MPU6050) | I²C | ✅ PASS | Accel `az≈+1 g` level; gyro `<0.25 deg/s` at rest after the hardened `calibrateGyro` (settle + pacing + motion-reject). |
| Battery (ADS7830) | I²C ch0 | ✅ FIXED | **Divider is ÷3, not ÷2** — metered 7.68 V pack reads 7.76 V (`DIVIDER_RATIO = 3`). |

**Servo turn-on — ✅ PASS (2026-06-01).** Required a firmware fix: `isp_i2c_pca9685` never cleared
the MODE1 **SLEEP** bit in its wake step — `!(MODE1_SLEEP & MODE1_RESTART)` ANDs two distinct bits
→ `0` → the mask was a no-op, so the chip ACKed but produced **no PWM**. Fixed (`&` → `|` so it
masks off both bits); all **13 servos now energize and hold at center** (90°/1500 µs). The
**leg↔channel map is verified correct** — FL=4/3/2, BL=7/6/5, BR=8/9/10, FR=11/12/13, head=15
(each commanded leg moved the matching physical leg). **Calibration note:** at center the **FL and
BR toes sit slightly lower** than the others → a small tibia trim is needed for the {FL,BR}
diagonal (the upcoming calibration step). Harnesses: `src/test_servo_center.spin2`,
`src/test_servo_wiggle.spin2`.

---

## License

MIT License - See [LICENSE](../LICENSE) for details.

---

*Part of the Iron Sheep Productions Propeller 2 Projects Collection*

---

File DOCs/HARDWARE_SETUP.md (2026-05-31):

# Hardware Setup — Mounting the P2 on the Robot Dog

A photo walk-through of how the **Propeller 2 (P2)** assembly was built and mounted in
place of the Raspberry Pi on the Freenove FNK0050 Robot Dog.







Three phases:

1. [Modeling the base](#1-modeling-the-base) — design and print the adapter plate.
2. [Assembling the P2 hardware](#2-assembling-the-p2-hardware-onto-the-base) — board + module onto the plate.
3. [Mounting on the robot](#3-mounting-on-the-robot) — drop it into the Pi's spot.

For the electrical side (power, signals, level-shifting) see
[`P2_MIGRATION_WIRING.md`](P2_MIGRATION_WIRING.md); the editable CAD lives in
[`P2-platform/`](P2-platform/).

---

## 1. Modeling the base

The adapter plate is modeled to match the Raspberry Pi's mounting footprint on the robot's
connection board, with raised standoff bosses positioned to carry the P2 Edge breakout
board. (Source model: `P2-platform/RoboDogP2PlateV2.3mf` — the V2 plate uses taller
standoffs.)

<p align="center">
  3D CAD model of the P2 mount plate
</p>

It took a few iterations to get the standoff height and hole alignment right. Here are
three printed test plates from that tuning process:

<p align="center">
  Three 3D-printed test plates
</p>

---

## 2. Assembling the P2 hardware onto the base

Everything laid out before assembly: the **P2 Edge Module (P2-EC32MB — 8 cores, 46 I/O,
32 MB)**, the **Parallax P2 Edge breakout board** (with its 5 VDC barrel jack and PropPlug
serial header), the printed mount plate, the screws / standoffs / hex nuts, and a couple of
screwdrivers.

<p align="center">
  Parts laid out for assembly
</p>

First the breakout board is fastened to the plate's standoffs. The barrel jack and PropPlug
programming header sit along the top edge:

<p align="center">
  Breakout board mounted to the plate
</p>

Then the P2 Edge Module seats into the breakout's edge connector:

<p align="center">
  P2 Edge Module mounted in the breakout board
</p>

Flipped over, you can see the hex nuts securing the board to the plate's standoffs (and the
PropPlug adapter peeking out at the left edge):

<p align="center">
  Underside of the mounted board showing fasteners
</p>

---

## 3. Mounting on the robot

With the Raspberry Pi removed, the robot's connection board is exposed and ready to receive
the P2 assembly:

<p align="center">
  Robot dog with connection board exposed, ready for the P2
</p>

The camera ribbon cable is taped down/insulated while working in the tight space:

<p align="center">
  Camera ribbon cable taped
</p>

And here's the finished result — the P2 assembly mounted where the Pi used to sit.

Seen from the **left**, the breakout board's edge faces forward: the 5 VDC barrel jack and
the PropPlug programming header sit right where they're easy to reach, and the P2's I/O
header runs along the side toward the robot's connection board:

<p align="center">
  Completed build, left angled view
</p>

From the **right**, you can see the P2 Edge Module itself standing proud on the breakout
board — the whole controller now rides in the Pi's old footprint while the legs, head-pan
servo, and ultrasonic "face" stay exactly as the kit shipped them:

<p align="center">
  Completed build, right angled view
</p>

---

## License

MIT License - See [LICENSE](../LICENSE) for details.

---

*Part of the Iron Sheep Productions Propeller 2 Projects Collection*

---

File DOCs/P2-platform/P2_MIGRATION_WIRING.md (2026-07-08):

# P2 Migration — Power & Wiring Map (replacing the Raspberry Pi)







Goal: drop a **Propeller 2 Edge Module + experiment/breakout board** in where the
Raspberry Pi sits, via an adapter that mates to the connection board's 40-pin header.

**Hardware on this build: PCB v1.0** (so the WS2812 LED data line is on **GPIO18**, the
`rpi_ws281x` path — see [`RPI_GPIO_USAGE.md`](../RPI_GPIO_USAGE.md)).

> ⚠️ **Confidence levels.** *Signal* assignments are **code-derived** (certain — traced in
> the server source). Power *direction* is **confirmed by Freenove's docs** (§1).
> **Bench-measured 2026-05-31** (Pi removed, P2 adapter not yet fitted): **5 V rail present**
> (pins 2/4); **grounds common** (6/9/14 at 0 V); **3.3 V rail absent** (#1 gotcha confirmed),
> pins 1/17 sitting at **~5 V**; and **no I²C pull-ups on the board** — SDA/SCL are open to both
> rails (the Pi's own ~1.8 kΩ pull-ups left with it). So the **P2 must supply 3.3 V pull-ups**
> and there is **no 5 V-idled-bus hazard** (§2, §4). The 3.3 V/5 V rails are **not bridged**
> (30+ MΩ) so the 5 V on pins 1/17 is benign leakage and the **MPU6050 (VDD max 3.46 V) is
> safe**. ~~Remaining: classify the SDA→GND 6.9 kΩ path and check the ECHO divider.~~
> **✅ All resolved — bring-up 2026-06-01 (P2 fitted, battery in):** the SDA→GND path is a real
> 6.9 kΩ resistor (use `PU_1K5`), ECHO is 5 V undivided (now read via a fitted ~1 kΩ series R into
> P9), and with the adapter's 3.3 V rail + P2 `PU_1K5` pull-ups **all three I²C devices answer**
> (0x40/0x48/0x68). Per-interface results: §7.

### Additional resources
- **Freenove FNK0050 official docs (Robot Dog):** https://docs.freenove.com/projects/fnk0050/en/latest/
  - Assembly + power switches: https://docs.freenove.com/projects/fnk0050/en/latest/fnk0050/codes/tutorial/2_Assemble_Robot.html
- **Battery info** (also in repo: `About_Battery.pdf`): the kit uses **2× 18650 Li-ion** cells.
  Battery list / purchase: https://github.com/Freenove/Freenove_Battery_List
- Companion docs in this repo: [`RPI_GPIO_USAGE.md`](../RPI_GPIO_USAGE.md), [`CLAUDE.md`](../../CLAUDE.md).

---

## 1. Direct answers

**Who powers whom?** The **robot powers the controller**, not the other way around —
**confirmed by Freenove's docs**: *"If you disconnect cable, the batteries will power
Raspberry Pi"* and *"all servos connect to the shield for power."* The battery pack feeds a
regulator on the connection board (shield), which delivers **5 V into the Pi's 40-pin
header** (pins 2 & 4). The Pi never powered the servos — 13 servos pull amps, far beyond
what a controller can source.

**Two power switches** (from the assembly docs): pressing **S1 and S2** lights two
indicators. **S1 = "Load"** gates the **servo** power rail (the docs have you toggle Load
off to install screws so the servos aren't energized); the other switch gates main/logic
(Pi) power. ➜ For P2 bring-up this is a gift: you can power the **P2 + logic with the Load
switch OFF** to test the **I²C devices** (servo controller, ADC, IMU) and code with the legs
de-powered, then enable servos. **Exception (measured 2026-05-31): the ultrasonic is on the
Load/servo rail** — it's only live with Load ON, so it can't be brought up in the legs-off mode;
support the robot when testing it.

**USB caveat:** a USB cable can power the Pi *in parallel* with the battery (*"you can still
use cable to power Raspberry Pi with switches ON"*) — but **USB does not charge the
batteries** (see Battery & charging below).

**What voltage is on the connector?**
- **5 V** — sourced *by the robot* (battery → board buck regulator), present on header
  **pins 2 & 4**. This is your input power for the P2 board.
- **3.3 V** — on header **pins 1 & 17**, but historically **generated by the Pi** and
  handed *out* to the connection board's logic/I²C pull-ups. **Remove the Pi and this rail
  vanishes** — your P2 adapter must *supply* 3.3 V back onto these pins if the board's I²C
  chips/pull-ups depend on it (very likely). This is the #1 gotcha.
  **Bench-confirmed 2026-05-31:** with the Pi removed, pins 1/17 are **not** at 3.3 V — they
  measure **~5 V** against grounds 6/9/14. The 5 V (vs floating) hints the rail may be
  resistively pulled toward 5 V; the §2 resistance test will say through what. The adapter
  must drive a real 3.3 V here.
- Battery voltage (7.4 V nom / 8.4 V full / 6.4 V cutoff — from `ADS7830.py`,
  `Server.battery_reminder`) stays on the board's servo/sensor rails; it is **not** exposed
  on the 40-pin header.

**5 V or 3.3 V for the P2?** The P2 is a **3.3 V part and its I/O is NOT 5 V tolerant**
(pin abs-max ≈ 3.6 V). You feed the P2 board **5 V** (it regulates to 3.3 V on-board), and
every *signal* line into a P2 pin must be ≤ 3.3 V. The good news: the Pi was also 3.3 V, so
the board was already built for 3.3 V logic — but the two 5 V-native sensors (ultrasonic,
WS2812) are the ones to watch (§4).

---

## 1b. Battery & charging — getting the device ready for use

Sourced from `About_Battery.pdf` (in this repo) + the FNK0050 docs + the software's own
voltage thresholds.

- **Cells:** **2× 18650 Li-ion**, **unprotected**, flat-top *or* button-top. **Not
  included** — buy separately (Freenove battery list above). Wired **2-series (2S)**.
- **Voltage (from `ADS7830.py` / `Server.py`):** **8.4 V** full (2 × 4.2 V), **7.4 V**
  nominal, software **low-battery cutoff at 6.4 V** → at/below that the server relaxes the
  legs and exits. The ADC reads the pack through a **÷3 divider** — **METERED 2026-06-01**:
  a 7.68 V pack reads raw **131** (≈ 2.57 V at the ADC pin), so pin = pack/3, **not** the
  `×2` in Freenove's `ADS7830.py` (`data/255 × 5.0 × 2`), which is wrong for this v1.0 board.
  `isp_battery_monitor` now uses `DIVIDER_RATIO = 3`; bring-up reads **7.76 V vs 7.68 V
  metered** (±1 LSB ≈ 59 mV through the divider).
- **⚠️ No on-board charging.** Direct quote: *"The control board connected to the USB cable
  will **not** charge the batteries. So you also need a charger."* You **remove the 18650
  cells and charge them in an external 18650 charger** (*"almost any charger suitable for
  18650 batteries can be used"*), then reinstall. There is **no charge port, no charge IC,
  and no in-place charging** on this board.
- **Readiness checklist before powering the robot:**
  - [ ] Charge both 18650s **fully (~4.2 V each / 8.4 V pack)** in an external charger.
  - [ ] Observe **polarity** — *"Don't reverse batteries. Or the board will be damaged."*
  - [ ] Insert cells **before** running servos (*"prepare the right batteries and fully
        charge them before assembling … without right batteries will … damage the servos"*).
  - [ ] Use a matched pair (same brand/capacity/charge state) for a 2S pack.
- **Implication for the P2 port:** the power-readiness story is **unchanged** by swapping in
  the P2 — you still hand-charge 18650s externally and the battery still feeds the shield's
  5 V regulator. The P2 board simply replaces the Pi as the 5 V load. If you want true
  in-place / USB charging you'd have to **add** a 2S charge circuit (e.g. a BMS/charger
  module) yourself; the kit has none.

## 2. Power architecture (rails inferred — verify each arrow)

```
  2S Li-ion pack ──► Board buck reg ──► 5V rail ─┬─► header pins 2,4  ──► (was) Pi 5V in
   7.4–8.4V         (on conn. board)             ├─► servo V+ (PCA9685 power)
                                                 ├─► HC-SR04 Vcc (5V)
                                                 └─► WS2812 Vcc (5V)

  Pi onboard 3.3V reg ──► header pins 1,17 ──► board I²C pull-ups + PCA9685/ADS7830/MPU6050 Vcc(logic?)
       (DISAPPEARS when the Pi is removed — P2 board must replace this source)
```

**Verify with a multimeter (Pi removed, battery off unless noted):**
1. **5 V rail** — power the board, measure header pin 2/4 → GND. Expect ~5 V. Confirm the
   regulator is rated for the P2's draw (P2 ≈ 0.1–0.4 A; trivially less than the Pi it
   replaced, so almost certainly fine).
2. **3.3 V provenance** — continuity/resistance from the I²C chips' Vcc and the SDA/SCL
   pull-up resistors to header **pins 1/17** vs. to the **5 V** rail. This tells you whether
   those chips run on 3.3 V (you must re-supply it) or on 5 V (then their I²C is pulled to
   5 V → you need level shifting — see §4).
3. **I²C pull-up rail** — measure SDA (pin 3) and SCL (pin 5) idle voltage with the board
   powered and a known-good 3.3 V applied to pins 1/17. Must idle at ~3.3 V, not 5 V.
4. **HC-SR04 ECHO divider** — check for a resistor divider on ECHO (pin 15) between the
   sensor and the header. If raw 5 V reaches the header pin, **do not** connect it to the
   P2 without adding one (§4).

### Bench measurements — 2026-05-31 (Pi removed, P2 adapter not yet fitted)

> **Protocol:** resistance/continuity readings are taken with the **batteries OUT** (fully
> de-energized) — required for valid ohmmeter readings. **Finding:** with the cells **in**, the
> board is partially energized **even with both switches OFF** (readings shift), so the pack
> feeds an **always-on path** (regulator input hard-wired to the battery and/or a standby /
> battery-sense rail). ⇒ expect **parasitic standby drain** — pull the 18650s for storage, or
> quantify the standby current. Voltage readings are taken batteries-in with the noted switch.

| Check | Result | Status |
|---|---|---|
| **5 V rail** (pins 2/4 → GND) | **~5 V present** | ✅ measured |
| **Grounds** (pins 6, 9, 14) | all **0 V** to each other (to the 3rd digit) → common ground | ✅ measured |
| **3.3 V rail** (pins 1/17 → GND) | **not 3.3 V — reads ~5 V** vs grounds 6/9/14 (no 3.3 V anywhere on the header) | ⚠️ #1 gotcha confirmed; rail absent |
| **I²C pull-ups** (unpowered Ω) | SDA(3)/SCL(5) → 3.3 V (1/17): **open** (≤ 0.8 MΩ); → 5 V (2/4): **8.8 MΩ** (both lines, both 5 V pins) | ✅ measured — **no board pull-ups on either rail** |
| **Rails bridged?** (pin 1 ↔ pin 2) | **30–33 MΩ** | ✅ measured — **not bridged** (5 V on 1/17 is leakage only) |
| **SDA / SCL → GND** (unpowered Ω) | SDA: **6.9 kΩ** (same both probe polarities) · SCL: **6.3 MΩ** | ✅ measured — **real ~6.9 kΩ pull-down on SDA** (not a diode) → use `PU_1K5` |
| **ECHO @ header** (pin 15 → GND) | **15.5 MΩ** — no divider lower-leg | ✅ measured — board does NOT divide ECHO |
| **HC-SR04 VCC / power** | **5 V**, on the 4-wire sensor cable; live **only with the Load/servo switch ON** | ✅ measured — ECHO = **5 V** ⇒ **~1 kΩ series R on P9**; ultrasonic not on logic power |

> **✅ Pull-up rail & 5 V hazard — RESOLVED.** No board pull-ups on SDA/SCL — the Raspberry
> Pi's own ~1.8 kΩ I²C-1 pull-ups to 3.3 V left **with the Pi** — and the 3.3 V/5 V rails are
> **not bridged** (30+ MΩ), so the 5 V on pins 1/17 is harmless leakage and the **MPU6050
> (VDD max 3.46 V) is not at risk**. There is **no 5 V-idled-bus hazard.** Action: the **P2
> supplies the I²C pull-ups to 3.3 V** (`isp_i2c_singleton` `PU_3K3`/`PU_1K5`, or external) and
> drives a real 3.3 V onto pins 1/17 — trivially overpowering the 30 MΩ leakage.
>
> **✅ SDA → GND = 6.9 kΩ — RESOLVED.** Same resistance in **both probe polarities** ⇒ a **real
> ~6.9 kΩ resistor (a pull-down on SDA)**, not an ESD diode; SCL has none (6.3 MΩ). It loads the
> bus high level, so **use the P2's strongest internal pull-up, `PU_1K5`** → SDA idles
> 3.3 × 6.9/(1.5 + 6.9) ≈ **2.71 V** (valid high; VIH ≈ 2.31 V). **Avoid `PU_3K3`** (≈ 2.2 V →
> fails). Add an external ~1 kΩ pull-up to 3.3 V for more margin if wanted. **Confirm SDA idles
> ≈ 2.7 V once powered.** The asymmetric pull-down's origin is unknown (no schematic) — worth
> understanding later; it does not block bring-up.

---

## 3. Wiring map: connection-board header → P2

Signal columns are **certain** (from code). The **P2-pin column is the as-built adapter map,
verified on hardware 2026-05-31**: base **P8**, with offsets **LED +0, ECHO +1, Buzzer +2,
TRIG +3, SCL +5, SDA +7** (P12 and P14 left spare). Rows are in P2-pin order.

| P2 pin | Robo hdr | BCM | Function (certain) | Notes |
|---|---|---|---|---|
| **P8** | 12 | GPIO18 | **WS2812 LED data** (PCB v1.0) | 3.3 V data into 5 V strip (§4) |
| **P9** | 15 | GPIO22 | **Ultrasonic ECHO** (input) | 5 V undivided → **~1 kΩ inline series R** + P2 clamp (§4); sensor live only with Load switch ON |
| **P10** | 11 | GPIO17 | **Buzzer** drive | P2 output; safe |
| **P11** | 13 | GPIO27 | **Ultrasonic TRIG** | P2 output (3.3 V triggers HC-SR04 fine) |
| **P12** | — | — | *spare* | unassigned |
| **P13** | 5 | GPIO3 | **I²C SCL** | 3.3 V open-drain; **P2 supplies pull-up (`PU_1K5`)** |
| **P14** | — | — | *spare* | unassigned |
| **P15** | 3 | GPIO2 | **I²C SDA** → PCA9685 (servos), ADS7830 (battery), MPU6050 (IMU) | **6.9 kΩ board pull-down → `PU_1K5`** |
| **P16** | — | — | **I²C SDA — bus 2 (voice)** → DF2301Q `0x64` | direct to the DFRobot module (not the robot header); see §3a |
| **P18** | — | — | **I²C SCL — bus 2 (voice)** → DF2301Q `0x64` | clock-stretched bus; master honors stretch; see §3a |
| — | 2, 4 | 5V | **Power IN from robot** → P2 board 5 V input | sized for the regulator (verify) |
| — | 1, 17 | 3.3V | **3.3 V** ← from P2 board 3.3 V out | feed *back* to board; chips' VDD + bus reference |
| — | 6,9,14,… | GND | Ground → **common GND** | tie robot GND ↔ P2 GND |

> Map is **as-built and verified on hardware** (2026-05-31) — not a proposal. ECHO carries a
> ~1 kΩ inline series resistor into P9 (5 V; P2 clamp). P12 and P14 are the **only spares left**:
> the **voice 2nd bus added P16/P18** (pin group 16, *outside* the original P8–P15 block).

### 3a. 2nd I²C bus — DF2301Q voice recognizer (P2-only addition)

A **DFRobot DF2301Q "Gravity" offline voice recognizer** (SKU SEN0539, I²C `0x64`) was added on the
P2 build — it is **not** part of the stock Freenove kit. It sits on a **separate 2nd I²C bus**
(P18 = SCL, P16 = SDA), owned by the **IO cog** (cog 1), so the two buses never cross cogs (bus 1 =
backend/cog 2; bus 2 = IO/cog 1). The module **clock-stretches** (holds SCL low while it prepares a
reply); the bus master (`isp_i2c`, the VAR/instance variant) honors the stretch with a bounded guard.

**Power & pull-ups (bus 2):**

| Item | Status | Note |
|---|---|---|
| Module supply | **✅ metered 2026-06-10 — 3.3 V** | DF2301Q powered at **3.3 V** from the adapter rail. |
| SDA/SCL pull-ups | **✅ resolved (working-driver precedent)** | The **bench-proven** driver on this hardware drives the **P2's strong internal pull-up, `PU_1K5`** — both the vendor quick-start (`VoiceSensor/USER-GUIDE.md`) and `custom_words_example` call `start(..., i2c.PU_1K5)`. Firmware matches: `isp_io_controller.VOICE_I2C_PULLUP = 1` (`PU_1K5`). The weaker `PU_3K3` can idle the bus low; `PU_NONE` would only suit a board with adequate external pull-ups (not what worked here). |
| Logic level | **✅ no hazard** | At 3.3 V the SDA/SCL idle high is ≈ 3.3 V — within the P2's range; **no clamp/level-shift needed** (unlike bus 1's 5 V ECHO). |

> **Bus 2 — fully resolved.** Supply **3.3 V** (metered 2026-06-10), pull-up `VOICE_I2C_PULLUP =
> PU_1K5` (matching the working voice driver — same pattern as bus 1's `PU_1K5`), and at 3.3 V the
> bus is within the P2's range so no level-shifting is required. No open bus-2 electrical items.

**P2 Edge reserved pins — don't use for robot I/O:** the Edge module uses **P58–P61** for
the boot SPI flash and **P62/P63** for the serial/programming host. The **P8–P15** block
chosen above sits safely inside the usable **P0–P57** range. The experiment/breakout board
supplies the module's 3.3 V from a 5 V input — that's the regulator you feed from the
robot's 5 V and tap to re-supply header pins 1/17.

---

## 4. 3.3 V vs 5 V — over-voltage handling (P2 pins clamp to VIO, ≤ ±10 mA)

| Line | Direction | Risk | Action |
|---|---|---|---|
| **I²C SDA/SCL** | bidir | **No board pull-ups** (open to both rails); **SDA has a real ~6.9 kΩ pull-down to GND** (2026-05-31, §2). Bus is 3.3 V — no 5 V hazard | **P2 supplies the pull-ups** — use the strongest internal mode **`PU_1K5`** so SDA idles ~2.71 V over the pull-down (valid high; **`PU_3K3` ≈ 2.2 V → fails**). **Applied:** `isp_i2c_ads7830` / `isp_i2c_mpu6050` / the bring-up console set `PU_1K5`; the seed `isp_i2c_pca9685`'s `PU_NONE` is overridden to `PU_1K5` via a **Spin2 OBJ CON override** at the call site (no seed edit). Optional external ~1 kΩ to 3.3 V for margin. |
| **Ultrasonic ECHO** | sensor→P2 | HC-SR04 echo = **5 V** (VCC measured 5 V, undivided) | **Fit a ~1 kΩ series R into P9** — the P2 pin clamps the 5 V to VIO (≤ 10 mA). Ultrasonic is powered only with the **Load/servo switch ON** (4-wire cable: GND/VCC/ECHO/TRIG) |
| **Ultrasonic TRIG** | P2→sensor | P2 drives 3.3 V; HC-SR04 trigger threshold usually OK | Safe; if flaky, level-shift up to 5 V |
| **Buzzer** | P2→board | Driving a transistor/driver from 3.3 V | Safe (output) |
| **WS2812 data** | P2→strip | 3.3 V data into a 5 V strip (data-high threshold ≈ 0.7·Vcc) | The Pi did this at 3.3 V already; usually works. If the first pixel is unreliable, add a 3.3→5 V level shifter (74AHCT125) or power the strip at ~4.3 V |
| **Voice SDA/SCL** (bus 2, P16/P18) | bidir | DF2301Q I²C at **3.3 V** (metered 2026-06-10) → idle high ≈ 3.3 V, **no hazard** | **No clamp/level-shift needed.** Pull-up: **`PU_1K5`** (P2 internal), per §3a — matches the working driver. |

P2 pins have **configurable drive strength / pull-ups / pull-downs** (P_HIGH_FLOAT / 1K5 /
15K / ~1 mA modes via the WRPIN M-field); set adequate drive for TRIG, buzzer, and the LED
data line, and use the internal pull-ups to source the (absent) I²C bus pull-ups to 3.3 V.

**P2 over-voltage clamp (datasheet).** Each P2 I/O pin has an internal **clamp diode to VIO**
(≈ 3.3 V); the abs-max "VIO + 0.3 V" is that diode's forward drop. The datasheet **explicitly
permits over-voltage** as long as the clamp's forward current stays **≤ ±10 mA**. So a P2 pin
safely *reads* a higher-voltage signal through a current-limiting series resistor:
R ≥ (Vin − 3.6 V) / 10 mA → for 5 V, R ≥ ~140 Ω; use **~1 kΩ** (≈ 1.4 mA) for margin. The clamp
current flows into VIO (trivial vs the P2's draw; raise R if that rail is ever lightly loaded).
*Caveats:* a **bare** pin must still stay ≤ VIO + 0.3 V, and the P2 cannot **drive** 5 V — the
series resistor is what makes reading 5 V safe. **The Raspberry Pi's GPIO, by contrast, is 3.3 V
and NOT 5 V-tolerant with no such clamp headroom** — which is itself a useful clue (next).

**ECHO is 5 V — RESOLVED (measured 2026-05-31).** pin 15 → GND = **15.5 MΩ** (no divider
lower-leg on the ECHO net) **and** the **HC-SR04 VCC = 5 V**, measured on the **4-wire sensor
cable** (GND/VCC/ECHO/TRIG — a direct passthrough to the daughterboard, no in-line divider). So
ECHO reaches header pin 15 as an **undivided 5 V** push-pull pulse. The
original Pi evidently tolerated this without a divider (not recommended); the **P2 does it
correctly with a ~1 kΩ series resistor into P9** — the pin clamps the 5 V to VIO with the
resistor holding clamp current to ~1.4 mA (≤ 10 mA).

**Power domain:** the ultrasonic is powered **only when the Load/servo switch is ON** — it is
*not* on the logic rail, so it can't be exercised in the legs-de-powered "safe" mode. Bring it
up with **Load on and the robot supported**.

---

## 5. What stays the same on the firmware side

Most of the robot is on **I²C**, so porting is mostly "implement an I²C master on the P2":
- **Servos** (PCA9685 @ `0x40`), **battery ADC** (ADS7830 @ `0x48`), **IMU** (MPU6050 @
  `0x68`) — all spoken to over the *same* I²C bus the Pi used. The P2 just needs an I²C
  master (smart-pin or bit-banged; OBEX has I²C objects). Register sequences, the 50 Hz
  servo timing, and the channel→leg map are documented in `CLAUDE.md` / `RPI_GPIO_USAGE.md`
  and translate 1:1.
- Only the **3 raw-GPIO devices** (buzzer, ultrasonic, WS2812) need P2-native pin code —
  the buzzer is trivial, the ultrasonic is a TRIG pulse + ECHO timing (a natural fit for a
  P2 smart pin in pulse-measure mode), and the WS2812 is a classic P2 smart-pin/streamer task.

---

## 6. Pre-wiring checklist

- [x] Meter the **5 V** rail on header pins 2/4 — **~5 V present (2026-05-31)**; still confirm the board regulator's current headroom.
- [~] Determine **3.3 V provenance** (pins 1/17) — **measured ~5 V, not 3.3 V (2026-05-31)**; rail is absent and pulled toward 5 V. Run the resistance test to find through what.
- [x] Confirm **I²C pull-up rail** is 3.3 V (not 5 V) — **RESOLVED (bring-up 2026-06-01)**: adapter
      supplies 3.3 V on 1/17, P2 drives `PU_1K5`, and all three I²C devices ACK (0x40/0x48/0x68).
- [x] **ECHO is 5 V, undivided** (pin 15→GND 15.5 MΩ; VCC 5 V, 2026-05-31) → **~1 kΩ series R into
      P9 fitted; ranging PASS 2026-06-01** (P2 pin clamp, ≤10 mA). Ultrasonic on the **Load/servo
      rail** — only live with Load ON.
- [~] Establish a single **common ground** — robot grounds (pins 6/9/14) **verified consistent at 0 V (2026-05-31)**; still tie robot GND ↔ P2 GND at wiring.
- [ ] Keep robot signals on **P0–P57**; leave **P58–P63** for flash/serial.
- [x] **Voice 2nd bus pull-up** — `VOICE_I2C_PULLUP = PU_1K5`, matching the bench-proven working driver
      (vendor quick-start + `custom_words_example` both use `i2c.PU_1K5`); §3a. **Resolved.**
- [x] **Voice module supply rail** — **metered 2026-06-10: 3.3 V** → idle high ≈ 3.3 V, **no clamp
      needed** (§3a, §4 voice row). All bus-2 electrical items closed.

---

## 7. Bring-up verification (2026-06-01)

P2 fitted on the adapter, battery installed. Each interface proven in isolation with a dedicated
`src/test_*.spin2` top file emitting P2 `DEBUG()` at 2 Mbaud (see `P2_BRINGUP_PLAYBOOK.md` for the
method and `src/README.md` §7 for the run recipe). Discrete-pin and bus facts confirmed:

| Interface | Pins | Result | Note |
|---|---|---|---|
| I²C bus | SCL P13 / SDA P15 | ✅ PASS | 0x40 PCA9685, 0x48 ADS7830, 0x68 MPU6050 (+0x70 = PCA9685 all-call). 3.3 V rail + `PU_1K5` confirmed. |
| WS2812 LED ring | P8 | ✅ PASS | Solid R/G/B (GRB order correct) + rainbow, all 7 px; 3.3 V data into 5 V strip works. |
| Buzzer | P10 | ✅ PASS | **Only sounds with the Load/servo switch ON** — the buzzer is on the Load rail, not logic power. |
| Ultrasonic | TRIG P11 / ECHO P9 | ✅ PASS | Tracks distance; **~1 kΩ inline series R into P9** handles the 5 V echo via the pin clamp. Load on. |
| IMU (MPU6050) | I²C | ✅ PASS | Accel `az≈+1 g` level; gyro `<0.25 deg/s` at rest after the hardened `calibrateGyro` (settle + pacing + motion-reject). |
| Battery (ADS7830) | I²C ch0 | ✅ FIXED | **Divider is ÷3, not ÷2** — metered 7.68 V pack reads 7.76 V (`DIVIDER_RATIO = 3`). |

**Servo turn-on — ✅ PASS (2026-06-01).** Required a firmware fix: `isp_i2c_pca9685` never cleared
the MODE1 **SLEEP** bit in its wake step — `!(MODE1_SLEEP & MODE1_RESTART)` ANDs two distinct bits
→ `0` → the mask was a no-op, so the chip ACKed but produced **no PWM**. Fixed (`&` → `|` so it
masks off both bits); all **13 servos now energize and hold at center** (90°/1500 µs). The
**leg↔channel map is verified correct** — FL=4/3/2, BL=7/6/5, BR=8/9/10, FR=11/12/13, head=15
(each commanded leg moved the matching physical leg). **Calibration note:** at center the **FL and
BR toes sit slightly lower** than the others → a small tibia trim is needed for the {FL,BR}
diagonal (the upcoming calibration step). Harnesses: `src/test_servo_center.spin2`,
`src/test_servo_wiggle.spin2`.

---

## License

MIT License - See [LICENSE](../../LICENSE) for details.

---

*Part of the Iron Sheep Productions Propeller 2 Projects Collection*

---

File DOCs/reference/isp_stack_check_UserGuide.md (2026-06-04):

# isp_stack_check - User Guide

A utility object for detecting stack overflow in Spin2 COG tasks on the Parallax Propeller 2. It fills a task stack with a known sentinel pattern before launch, then checks at runtime whether the sentinel has been overwritten -- catching overflows that would otherwise silently corrupt memory.

- **Author:** Stephen M. Moraco, Iron Sheep Productions, LLC
- **License:** MIT
- **Dependencies:** None

---

## Why You Need This

When you launch a Spin2 method in a new COG with `cogspin()`, you provide a stack buffer. If the method's call depth or local variables exceed that buffer, the stack silently overwrites whatever memory follows it. This object detects that situation by:

1. Filling the stack with a recognizable pattern (`$a5a50df0`) before launch
2. Placing a sentinel value (`$addee5e5`) immediately after the last stack long
3. Checking at runtime whether the sentinel is still intact

If the sentinel has been overwritten, the COG halts with a debug message -- giving you a clear signal instead of mysterious corruption.

---

## Quick Start

```spin2
OBJ
    stack_check : "isp_stack_check"

CON
    TASK_STACK_LONGS = 128

DAT
    taskStack       LONG    0[TASK_STACK_LONGS]
    endStackMark    LONG    stack_check.DO_NOT_WRITE_MARK       ' sentinel after stack

PUB startTask()
    ' Step 1: Prepare the stack (fill with pattern + set sentinel)
    stack_check.prepStackForCheck(@taskStack, TASK_STACK_LONGS)

    ' Step 2: Launch the COG
    cogspin(NEWCOG, myTask(), @taskStack)

PRI myTask()
    repeat
        ' Step 3: Check for overflow each iteration
        stack_check.checkStack(@taskStack, TASK_STACK_LONGS)
        ' ... do work ...
```

---

## Public API Reference

### Constants

| Constant | Value | Description |
|---|---|---|
| `DO_NOT_WRITE_MARK` | `$addee5e5` | Sentinel placed after the last stack long; overflow detected if overwritten |
| `NOT_WRITTEN_MARK` | `$a5a50df0` | Fill pattern written to every stack long before launch |
| `TST_UNKNOWN` | `0` | Test result: unknown |
| `TST_PASS` | `1` | Test result: pass |
| `TST_FAIL` | `2` | Test result: fail |

### Methods

| Method | Signature | Description |
|---|---|---|
| `prepStackForCheck` | `(pStack, nStackLongCt)` | Fill stack with `NOT_WRITTEN_MARK` and write `DO_NOT_WRITE_MARK` sentinel at `pStack[nStackLongCt]` |
| `checkStack` | `(pStack, nStackLongCt)` | Verify sentinel is intact. If overwritten: emit debug message and **halt the COG** |
| `reportStackUse` | `(pStack, nStackLongCt)` | Count how many longs were used and print `"^^^ STACK used N of M"` to debug |
| `testReport` | `(pStack, nStackLongCt, pTestId, bPassFail)` | Print pass/fail result, report stack usage, check for overflow. **Halts on failure** |
| `dumpStack` | `(pStack, nStackLongCt)` | Hex dump the entire stack contents to debug |
| `dbgMemDump` | `(pMessage, pBytes, lenBytes)` | General-purpose hex memory dump (16 bytes per row with addresses) |

### Parameter Reference

- **pStack** -- Pointer to the first long of the stack buffer (e.g., `@taskStack`)
- **nStackLongCt** -- Number of longs in the stack buffer (not bytes -- longs)
- **pTestId** -- Pointer to a zero-terminated string identifying the test
- **bPassFail** -- `TST_PASS` (1) or `TST_FAIL` (2)

---

## The Three-Phase Usage Pattern

Every production use follows the same three phases:

### Phase 1: Declare Stack + Sentinel (DAT section)

```spin2
CON
    STACK_SIZE_LONGS = 128

DAT
    taskStack       LONG    0[STACK_SIZE_LONGS]
    endStackMark    LONG    stack_check.DO_NOT_WRITE_MARK
```

The sentinel long **must** be declared immediately after the stack buffer in DAT. This places it at the exact memory address the object will check. At compile time, it holds `$addee5e5`; at runtime, `prepStackForCheck()` also writes this value programmatically.

### Phase 2: Prepare Before `cogspin()` (startup method)

```spin2
PUB start()
    stack_check.prepStackForCheck(@taskStack, STACK_SIZE_LONGS)
    cogspin(NEWCOG, myTask(), @taskStack)
```

This fills every stack long with `$a5a50df0` and writes the sentinel at position `[STACK_SIZE_LONGS]`. Call this **before** `cogspin()` -- it must run before the task starts using the stack.

### Phase 3: Check at Runtime (inside the COG task)

```spin2
PRI myTask()
    repeat
        stack_check.checkStack(@taskStack, STACK_SIZE_LONGS)
        ' ... do work ...
```

If the sentinel has been overwritten, `checkStack()` prints `"^^^ STACK Overflow! Depth greater than N longs"` to debug and halts the COG in an infinite loop for analysis.

---

## Real-World Usage Patterns

The following patterns are drawn from 3 production projects across 7 consumer files.

### Pattern 1: Single COG with Periodic Checking

The most common pattern -- one background task with a check at the top of each loop iteration.

**Sensor driver COG** (from P2-Magnetic-Imaging-Tile, `isp_tile_sensor.spin2`):

```spin2
OBJ
    fifo        : "isp_frame_fifo_manager"
    stack_check : "isp_stack_check"

CON
    SENSOR_STACK_SIZE_LONGS = 128

DAT
    sensor_cog_stack    LONG    0[SENSOR_STACK_SIZE_LONGS]
    sensor_stack_mark   LONG    stack_check.DO_NOT_WRITE_MARK

PUB start(sensor_base_pin) : success
    stack_check.prepStackForCheck(@sensor_cog_stack, SENSOR_STACK_SIZE_LONGS)
    cog_id := cogspin(NEWCOG, sensor_loop(), @sensor_cog_stack)

PRI sensor_loop()
    configure_smart_pins()

    repeat
        stack_check.checkStack(@sensor_cog_stack, SENSOR_STACK_SIZE_LONGS)
        ' ... read sensor, push frames to FIFO ...
```

---

### Pattern 2: Granular Checking Around Deep Call Chains

When your COG task calls multiple initialization routines with deep call chains, check the stack **after each one** to pinpoint exactly which routine overflows.

**OLED display COG** (from P2-Magnetic-Imaging-Tile, `isp_oled_single_cog.spin2`):

```spin2
CON
    OLED_STACK_SIZE_LONGS = 128

DAT
    display_cog_stack   LONG    0[OLED_STACK_SIZE_LONGS]
    display_stack_mark  LONG    stack_check.DO_NOT_WRITE_MARK

PRI display_loop()
    ' Check BEFORE init (baseline)
    stack_check.checkStack(@display_cog_stack, OLED_STACK_SIZE_LONGS)

    init_hardware()
    ' Check AFTER init_hardware
    stack_check.checkStack(@display_cog_stack, OLED_STACK_SIZE_LONGS)

    init_color_lut()
    ' Check AFTER init_color_lut
    stack_check.checkStack(@display_cog_stack, OLED_STACK_SIZE_LONGS)

    init_cell_origin_lut()
    ' Check AFTER init_cell_origin_lut
    stack_check.checkStack(@display_cog_stack, OLED_STACK_SIZE_LONGS)

    ' Main loop
    repeat
        stack_check.checkStack(@display_cog_stack, OLED_STACK_SIZE_LONGS)
        ' ... render frames ...
```

**HDMI display COG** (from P2-Magnetic-Imaging-Tile, `isp_hdmi_display_engine.spin2`) follows the same granular pattern:

```spin2
PRI display_loop()
    stack_check.checkStack(@display_cog_stack, HDMI_STACK_SIZE_LONGS)
    gfx.start()
    stack_check.checkStack(@display_cog_stack, HDMI_STACK_SIZE_LONGS)

    gfx.cls($00_00_00)
    stack_check.checkStack(@display_cog_stack, HDMI_STACK_SIZE_LONGS)

    gfx.DrawSensorGrid(GRID_X, GRID_Y, CELL_SIZE, CELL_GAP)
    stack_check.checkStack(@display_cog_stack, HDMI_STACK_SIZE_LONGS)

    DrawStaticLabels()
    stack_check.checkStack(@display_cog_stack, HDMI_STACK_SIZE_LONGS)

    repeat
        stack_check.checkStack(@display_cog_stack, HDMI_STACK_SIZE_LONGS)
        ' ... process FIFO frames, update display ...
```

This approach is invaluable during development -- if `init_color_lut()` overflows, you see the halt **immediately** after that call instead of some time later in the main loop.

---

### Pattern 3: Multiple COG Stacks in One Object

When an object launches more than one COG, each stack gets its own buffer, sentinel, and prep call.

**Serial receiver with watchdog** (from P2-Magnetic-Imaging-Tile REF, `isp_string_receiver.spin2`):

```spin2
OBJ
    RPi         : "isp_serial"
    stack_util  : "isp_stack_check"
    strQ        : "isp_string_queue"

CON
    STACK_SIZE_LONGS = 96       ' 48 and 32 crash!

DAT
    ' Watchdog COG stack
    taskWdStack     LONG    0[STACK_SIZE_LONGS]
    endWdStackMark  LONG    stack_util.DO_NOT_WRITE_MARK

    ' Serial receive COG stack
    taskRxStack     LONG    0[STACK_SIZE_LONGS]
    endRxStackMark  LONG    stack_util.DO_NOT_WRITE_MARK

PUB start()
    ' Prepare BOTH stacks
    stack_util.prepStackForCheck(@taskRxStack, STACK_SIZE_LONGS)
    stack_util.prepStackForCheck(@taskWdStack, STACK_SIZE_LONGS)

    ' Launch serial receive COG
    rxCogId := cogspin(NEWCOG, TaskSerialRx(@serialRxBffr, RX_CHR_Q_MAX_BYTES), @taskRxStack)

    ' Launch watchdog COG (elsewhere)
    wdCogId := cogspin(NEWCOG, TaskCidHealthWd(), @taskWdStack)

PRI TaskSerialRx(pRxBffr, lenRxBffr)
    repeat
        stack_util.checkStack(@taskRxStack, STACK_SIZE_LONGS)
        ' ... receive characters ...

PRI TaskCidHealthWd()
    repeat
        stack_util.checkStack(@taskWdStack, STACK_SIZE_LONGS)
        ' ... monitor health ...
```

Note the comment `' 48 and 32 crash!` -- this is exactly the kind of discovery `isp_stack_check` enables. The developer tried smaller stacks, detected the overflow, and increased to 96.

---

### Pattern 4: Checking from Both the Task and Its Callers

You can call `checkStack()` from the COG that owns the stack **and** from the main COG that calls methods which interact with the task's data. This catches overflow regardless of which COG detects it first.

**COG-offloader pattern** (from P2-OctoSerial, `isp_octoport_serial.spin2` -- currently commented out):

```spin2
CON
    STACK_SIZE_LONGS = 64

DAT
    taskStack       LONG    0[STACK_SIZE_LONGS]
    endStackMark    LONG    stack_util.DO_NOT_WRITE_MARK

PUB addPort(rxp, txp, mode, baudrate, txPullup) : portHandle
    stack_util.prepStackForCheck(@taskStack, STACK_SIZE_LONGS)
    ' ... launch background task ...

PRI taskUnloadStringToQ()
    repeat
        ' Check from WITHIN the background task
        stack_util.checkStack(@taskStack, STACK_SIZE_LONGS)
        ' ... process strings ...

PUB getRxString(pUserBuf, nBufLen) : pNextString
    ' Check from the CALLING COG (main program)
    stack_util.checkStack(@taskStack, STACK_SIZE_LONGS)
    ' ... dequeue string ...
```

---

### Pattern 5: Unit Test Reporting with `testReport()`

The `testReport()` method combines pass/fail reporting with stack usage analysis -- useful for automated testing.

**Queue overrun tests** (from P2-Magnetic-Imaging-Tile REF, `isp_string_receiver.spin2`):

```spin2
CON
    #0, TST_UNKNOWN, TST_PASS, TST_FAIL        ' from isp_stack_check

PRI runTests() | bPassFail, bQueOverrun
    ' Test 1: Should detect overrun
    bQueOverrun := fillQueuePastCapacity()
    bPassFail := (bQueOverrun == TRUE) ? TST_PASS : TST_FAIL
    stack_util.testReport(@taskRxStack, STACK_SIZE_LONGS, string("(1) Rx too many"), bPassFail)

    ' Test 2: Should NOT overrun
    bQueOverrun := fillQueueToExactCapacity()
    bPassFail := (bQueOverrun == FALSE) ? TST_PASS : TST_FAIL
    stack_util.testReport(@taskRxStack, STACK_SIZE_LONGS, string("(2) Rx Exact full"), bPassFail)

    ' Test 3: Wrap-around test
    bQueOverrun := wrapAroundTest()
    bPassFail := (bQueOverrun == FALSE) ? TST_PASS : TST_FAIL
    stack_util.testReport(@taskRxStack, STACK_SIZE_LONGS, string("(3) Rx wrap test"), bPassFail)
```

Debug output from `testReport()` looks like:

```
+++ ---------
+++ TEST [(1) Rx too many] - pass
^^^ STACK used 47 of 96
```

On failure, the output includes `FAIL` and the COG halts for analysis.

---

## Stack Sizing Guidelines

| Task Complexity | Recommended Size | Notes |
|---|---|---|
| Simple loop, few locals | 32-64 longs | Clock tasks, simple watchdogs |
| Moderate (serial I/O, queues) | 64-96 longs | String processing, protocol handlers |
| Complex (display drivers, deep call chains) | 128+ longs | Graphics init, multi-stage pipelines |

**How to right-size a stack:**

1. Start with a generous allocation (e.g., 128 longs)
2. Add `reportStackUse()` calls to see actual high-water mark
3. Reduce the allocation to ~1.5x the reported usage
4. Keep `checkStack()` in your main loop as ongoing protection

---

## Tips and Best Practices

1. **Always place the sentinel immediately after the stack in DAT.** The `LONG stack_check.DO_NOT_WRITE_MARK` must be the very next long after `LONG 0[SIZE]` -- no gaps, no other variables between them.

2. **Call `prepStackForCheck()` before `cogspin()`.** The fill pattern enables both overflow detection and usage reporting. Without it, `reportStackUse()` cannot distinguish used from unused longs.

3. **Use granular checking during development.** Place `checkStack()` calls after every major function call to pinpoint exactly which routine causes overflow. You can remove the extra checks once the stack is right-sized.

4. **The `reportStackUse()` method counts from the bottom up.** It stops at the first long that still contains `NOT_WRITTEN_MARK`, reporting everything below that as "used." This gives you a high-water mark for sizing.

5. **`checkStack()` halts on overflow.** When it detects the sentinel has been overwritten, it enters an infinite `repeat` loop. This is intentional -- it freezes the COG so you can examine debug output and memory state.

6. **Common object prefixes** seen across production code:
   - `stack_check` -- used in newer projects (P2-Magnetic-Imaging-Tile src/)
   - `stack_util` -- used in older projects (P2-OctoSerial, REF code)

7. **Use `dbgMemDump()` as a standalone utility.** It works on any memory region, not just stacks -- useful for inspecting buffers, register maps, or data structures during debugging.

---

## Projects Using This Object

| Project | Consumer Files | Stacks Monitored | Primary Use Case |
|---|---|---|---|
| P2-Magnetic-Imaging-Tile (src/) | 3 files | 3 COG stacks (OLED, HDMI, Sensor) | Display and sensor driver overflow protection |
| P2-Magnetic-Imaging-Tile (REF/) | 3 files | 4 COG stacks (clock, display, watchdog, serial Rx) | Multi-COG overflow detection + unit test reporting |
| P2-OctoSerial | 1 file (commented out) | 1 COG stack (string queue offloader) | Background task overflow detection |
| P2-uSD-FAT32-FS | 0 files | -- | Present but currently unused |

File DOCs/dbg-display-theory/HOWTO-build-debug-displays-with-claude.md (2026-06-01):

# How We Build P2 DEBUG Displays — Claude Code + Pillow + pnut-term-ts







A reproducible account of how Claude Code and Stephen built a **graphical servo-calibration
panel** for the P2 Robot Dog — a `DEBUG(\`PLOT ...)` instrument window with live numeric readouts,
keyboard control, and real-time servo motion — and the **collaboration pattern** that made it work
even though the agent can't see a GUI. The point: *building P2 debug displays is a skill you can
hand to Claude Code.* This shows you how, end to end, so you can do it again.

> **Companion knowledge (versioned in this repo, read first):**
> [`THEORY-OF-OPERATION-crop-overlay.md`](THEORY-OF-OPERATION-crop-overlay.md) (deep dive on the
> crop-&-overlay/sprite-blit technique) and
> [`DISPLAY-PATTERNS-builders-guide.md`](DISPLAY-PATTERNS-builders-guide.md) (the reusable recipe,
> sprite patterns, and `pc_key`/`pc_mouse` input). This doc assumes those as background and focuses
> on **our** workflow, the Python tooling, and the gotchas we hit.

---

## 1. What we built

`src/test_cal_full.spin2` — a `{Spin2_v50}` PLOT window that:
- shows the **selected leg + joint** (e.g. *FRONT-LEFT · shoulder*) and its **trim value** as large
  sprite digits,
- lets you **navigate** all 13 servos (`j` = next joint, `l` = next leg) and **trim** each
  (`a`/`d` = ∓1°, `q`/`e` = ∓5°),
- drives the **real servo** live as you trim (via `isp_i2c_pca9685.gotoMicroSec`),
- **dumps the whole calibration table** to the log (`p`) so the values can be baked into firmware.

It grew from `src/test_cal_display.spin2` (increment 1 — a single joint), which we built first to
prove the pipeline. **Build small, confirm on hardware, then scale** — see §6.

---

## 2. The toolchain & the "I can't see your screen" workflow

| Tool | Role |
|---|---|
| `pnut-ts -d` | Spin2/PASM2 compiler (Iron Sheep). `-d` compiles `DEBUG()` in. Accepts `{Spin2_v50}` PLOT syntax. |
| `pnut-term-ts` | Debug terminal. **Headless** (`--headless`) for CI/agent runs; **windowed** (default) renders PLOT windows + reads keyboard/mouse. |
| **Python 3 + Pillow** | Generates the BMP artwork (backgrounds, fonts, sprite strips). |

**The key constraint and how we beat it:** the agent runs `pnut-term-ts` *headless* (no display), so
**Claude cannot see a PLOT window or send keystrokes**. But `pnut-term-ts` **mirrors every byte of
P2 output to a log file even in windowed mode** — `src/logs/debug_*.log` (relative to where you run
it). So the loop is:

```
Claude:  writes Spin2 + generates BMPs + compiles  ──▶  hands over the run command
Stephen: runs the WINDOWED terminal, sees the panel, uses the keyboard, saves with `p`
Claude:  reads src/logs/debug_*.log  ──▶  sees exactly what Stephen saw, bakes values into code
```

Claude sees everything the user sees, through the log. That single fact makes graphical,
interactive display work tractable for an agent that has no screen.

**Run commands** (note `-b 2000000` — see gotchas):
```bash
pnut-ts -d -q src/test_cal_full.spin2                         # compile (Claude)
cd src && pnut-term-ts -r test_cal_full.bin -b 2000000        # run windowed (Stephen)
```
Run from `src/` so the bare BMP filenames in `LAYER` resolve, and so the log lands in `src/logs/`.

---

## 3. Generating the artwork with Python (Pillow)

DEBUG `LAYER` requires **24-bit, uncompressed (BI_RGB), no-alpha BMP**. Pillow produces exactly that
for an `RGB` image with `img.save("x.bmp")`. Our generator is `tools/gen_cal_assets.py`.

Two sprite patterns (from the builders' guide) drive the art:
- **Font/atlas strip** (`cal_font.bmp`): one row of equal cells `0123456789-+`, 40×60 px each; a
  digit is selected by `srcX = index*40`. Unlimited numbers from one small image.
- **Word strips** (`panel_legs.bmp`, `panel_joints.bmp`): the leg names and joint names stacked as
  fixed-height cells; the active one is blitted by `srcY = index*cellH`. Changing the on-screen leg
  is "copy a different row," no text rendering on the P2.

Plus one **background** (`panel_bg.bmp`): the static frame — title, the black value box, labels, and
the key-help footer.

**The trick that keeps blind builds correct — coordinates as a single source of truth.** The Python
script defines the layout (box position, cell sizes, slot X/Y) *once*, draws the BMPs from those
numbers, **and prints a ready-to-paste Spin2 `CON` block** of the same constants. The Spin2 and the
artwork therefore can't drift. After any layout change: re-run the generator, paste the printed
`CON` values, recompile.

```bash
python3 tools/gen_cal_assets.py     # writes the .bmp files + prints the Spin2 CON layout block
```

To eyeball a BMP without a viewer, convert to PNG and look:
`python3 -c "from PIL import Image; Image.open('src/panel_bg.bmp').save('/tmp/x.png')"` — Claude can
read the PNG to verify the art rendered correctly before you ever run it.

---

## 4. The Spin2 side (DEBUG PLOT essentials we used)

- First line must be `{Spin2_v50}`.
- **Window:** `DEBUG(\`plot cal title 'P2 Servo Cal' size 480 240 pos 380 180 hidexy update)` —
  `hidexy update` = manual/double-buffered (no flicker; nothing shows until `\`cal update`).
- **Load art once:** `DEBUG(\`cal layer 1 'panel_bg.bmp')` … (layers 1–4 here).
- **Compose a frame:** erase by restoring background (`\`cal crop 1 \`(boxX,boxY,boxW,boxH)`), blit
  sprites (`\`cal crop 2 \`(srcX,0,w,h, destX,destY)`), then one `\`cal update`.
- **Input:** `DEBUG(\`cal \`pc_key(@keyCode))` — must be the **last** thing in its `DEBUG()`
  statement; returns one key (ASCII for letters). The window must have focus.
- Dynamic args use the nested backtick form `` \`(expr, expr, …) ``; constants can be written bare.

---

## 5. Gotchas we actually hit (save yourself the round-trips)

- **`-b 2000000` is mandatory on `pnut-term-ts`.** Headless opens the port at 115200 for the
  *download* (fine) but does **not** auto-apply the debug baud to the *runtime* read — without
  `-b 2000000` the 2 Mbaud `DEBUG` stream is garbage. Set `DEBUG_BAUD = 2_000_000` in the source too.
- **Use `abs(x)`, not `||x`.** pnut-ts rejects the `||` absolute-value operator ("Expected an
  expression term").
- **Use `>=` / `<=`, not `=>` / `=<`.** The `=>`/`=<` forms (seen in some P1-era examples) fail in
  pnut-ts ("Expected end of line"). (Clamp operators `#>` / `<#` are fine.)
- **BMP path resolution is relative to the terminal's working dir** — run from `src/` so bare
  `LAYER 'name.bmp'` finds the files (and the log lands in `src/logs/`).
- **Sprite cells are opaque** (no alpha): each cell must carry the right background so blits leave no
  seam — the digit/word cells use the *same* black/panel color as the box/background behind them.
- **Headless ≠ windowed.** PLOT windows and `pc_key` only work in the windowed terminal; that's why
  the human runs it and the agent reads the log.

---

## 6. The collaboration pattern (why it worked)

1. **Prove the pipeline on one element first.** Increment 1 was a single joint — it exercised every
   risky piece at once (window, BMP load, sprite blit, `pc_key`, live servo). Once that rendered and
   moved a servo on Stephen's bench, scaling to 13 joints was mostly replication.
2. **Make the agent verifiable without a screen.** Generate art → convert to PNG → Claude reads it.
   Run on hardware → Claude reads `src/logs/debug_*.log`. Every step has a text artifact the agent
   can inspect.
3. **Single source of truth for anything shared between art and code** (the layout constants).
4. **Commit each validated increment** so there's always a working restore point.

This is a repeatable skill: *describe the instrument you want; Claude designs the layout, generates
the BMPs with Pillow, writes the `{Spin2_v50}` PLOT code, and compiles; you run the windowed terminal
and report; Claude reads the log and iterates.* It works for gauges, scopes, control panels, and —
as here — hardware calibration rigs.

---

## License

MIT License - See [LICENSE](../../LICENSE) for details.

---

*Part of the Iron Sheep Productions Propeller 2 Projects Collection*

---

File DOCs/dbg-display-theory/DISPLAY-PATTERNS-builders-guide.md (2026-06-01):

# P2 DEBUG-Plot Displays — Builder's Guide & Contrast

**Purpose:** a reference an agent can use to build new Propeller-2 `DEBUG(\`PLOT ...)` "instrument panel" displays in the style of Jon McPhalen's examples. It contrasts four working displays, extracts the reusable recipe, and documents how a display can also be an **input device** (PC keyboard + mouse).

**Companion doc:** `THEORY-OF-OPERATION-crop-overlay.md` (deep dive on the analog meter).

**Hard requirement:** all of these use V50 layer/crop commands. The source file must start with `{Spin2_v50}` (or later), and the toolchain must be PNut/Spin2 v50+.

---

## 0. The mental model in one paragraph

A PLOT window owns up to **8 off-screen image buffers ("layers")**, each loaded from a BMP. The visible canvas is composed by **copying rectangles out of those layers** (`CROP`) and then **flipping the result to screen** (`UPDATE`). Artwork is authored as BMP files — the P2 never draws pixels, it only issues *"copy this rectangle to there"* commands plus a little arithmetic to pick which rectangle and where. This is sprite-sheet blitting. Optionally the same window reads the host **keyboard and mouse** back into the P2, turning a picture into a control panel.

---

## 1. The four reference displays at a glance

| # | File | Window title | What it shows | Layers used | Vector draw? | Reads input? |
|---|---|---|---|---|---|---|
| 1 | `jm_debug_panel_010.spin2` | Binary LEDS | 8 LEDs = one byte (red/green) | 3 (whole-panel states) | no | no |
| 2 | `jm_debug_panel_digits_020.spin2` | Digital Display | 6-digit number + 8 LEDs | 3 (2 panel states + 1 font) | no | no |
| 3 | `jm_debug_analog_meter_050.spin2` | Analog Meter+ | Needle gauge + 4-digit readout | 1 (packed: bg + font) | **yes** (CORDIC needle) | no |
| 4 | `jm_debug_switches_030.spin2` | Binary Switches | 8 toggle switches + multi-radix readout | 5 (2 states + 3 fonts/labels) | no | **yes** (key + mouse) |

These four span the whole design space: output-only → interactive, single-layer → many-layer, pure-blit → blit+vector. Build new displays by mixing these patterns.

---

## 2. The common skeleton (every display follows this)

```spin2
{Spin2_v50}

con
  CLK_FREQ = 200_000_000
  _clkfreq = CLK_FREQ

pub main()
  setup()
  repeat
    ' ... compute state ...
    ' ... CROP sprites for changed elements ...
    debug(`NAME update)              ' flip frame to screen
    waitms(...)

pub setup()
  debug(`plot NAME title 'Title' size W H pos X Y hidexy update)   ' create window
  debug(`NAME layer 1 'background.bmp')                            ' load art
  debug(`NAME layer 2 'sprites.bmp')
  debug(`NAME crop 1)                                              ' paint full background
  debug(`NAME update)                                              ' show it
```

- `` `NAME `` is the window handle you pick (`amp`, `panel`, `switches`, …). Every later command targets it.
- `hidexy` hides the on-screen measurement cursor; `update` puts the window in **manual / double-buffered** mode — nothing shows until you call `update`. **This is what kills flicker:** issue all the frame's crops, then one `update`.
- Load all layers once in `setup()`. They persist for the life of the window.

---

## 3. The three commands you actually use

### `LAYER n 'file.bmp'`
Load a BMP into off-screen buffer `n` (1–8). No visible effect.

### `CROP` — three forms (memorize the argument order)
```
crop n                              ' (a) repaint ENTIRE layer n at origin — full background / full wipe
crop n  left top width height      ' (b) copy that source rect back to the SAME spot — "erase by restore"
crop n  left top width height x y   ' (c) copy source rect (left,top,w,h) to DESTINATION (x,y) — "blit a sprite"
```
> Argument order is **source rectangle first, destination last**. The single biggest source of bugs.

### `UPDATE`
Flip the composed frame to screen. Call once per frame after all crops.

**The three idioms built from these:**
- **Draw/replace a cell:** form (c) — pick source by data, pick dest by slot index.
- **Erase a region:** form (b) — copy clean background over it. (There is no "clear"; you restore.)
- **Reset whole scene:** form (a) — repaint the entire background layer.

---

## 4. Coordinate systems — pick one deliberately

| Mode | Set with | Origin | Y direction | Used by |
|---|---|---|---|---|
| Default | (nothing) | top-left | Y **down** | panel_010, panel_digits |
| Cartesian | `NAME cartesian 1` | bottom-left | Y **up** | switches |
| Cartesian + precise | `NAME cartesian 1 0 precise` | bottom-left | Y up, **×256 sub-pixel** | analog_meter |

`precise` multiplies all coordinates by 256 (you write `160<<8` for x=160), giving smooth sub-pixel vector lines — needed for the needle. In precise mode `linesize $400` means 4.0 px (4×256).

> When adapting coordinates between examples, first check which mode the source used — a y value means opposite things under default vs cartesian.

---

## 5. Sprite-sheet design patterns (the heart of it)

There are exactly two ways these examples encode visual state into BMP layers. New displays combine them.

### Pattern A — "whole-state layers": one full-canvas BMP per state
Each possible look is a complete background image; you pick the **layer number** to choose state, then crop the small piece you need from that layer at its own location.

- **panel_010** (`leds_off`/`leds_red`/`leds_grn`, all 480×120): the 8-LED bar in three states. To set one LED: `crop layer x y 50 50` where `layer` ∈ {1,2,3} selects off/red/green and `(x,y)` is that LED's fixed slot (form b — source = dest).
  ```spin2
  img := value.[bit] + 1 + (ledcolor * value.[bit])   ' 1=off, 2=red, 3=green
  debug(`panel crop `(img, x, y, 50, 50))             ' same-spot copy from chosen layer
  ```
- **panel_digits** (`panel_leds_off`/`panel_leds_on`): the whole panel with LEDs dark vs lit; an LED is `img := value.[bit] + 1` then `crop img x y 50 50`.
- **switches** (`p2_debug_swtiches0`/`swtiches1`): switch-bank with all toggles down vs up; one switch is `crop layer sx sy 21 51` at its slot.

> Strength: trivial code, pixel-perfect alignment (source and dest coincide). Cost: one full BMP per state, so it suits a small number of states (on/off, off/red/green).

### Pattern B — "font/atlas strips": one BMP holds many glyphs in a row (or grid)
The glyph is selected by arithmetic into the strip; destination is a layout slot. This is how all numeric readouts work.

| Sheet | Size | Cell | Index formula | Notes |
|---|---|---|---|---|
| `panel_digits.bmp` | 484×54 | 44×54 | `srcX = digit*44` | `0–9` then `–` (minus at x=440) |
| `hex_digits.bmp` | 561×50 | 33×50 | `srcX = digit*33` | `0–9 A b C d E F –` (sign at x=528) |
| analog meter font (rows 240–539 of the packed sheet) | 45×60 cells | `srcX = digit*45`, `srcY = 240 + color*60` | color picks the **row**: RED..WHITE |

Render loop (right-to-left, leading-zero suppression):
```spin2
repeat i from 0 to 5
  d  := value // base                       ' least-significant digit
  x1 := <slot for column i>
  if (i == 0) || (value)                    ' always show ones; suppress leading zeros
    debug(`NAME crop FONT `(d*CELLW, srcY, CELLW, CELLH, x1, destY))   ' blit glyph (form c)
  else
    if negative: blit the sign glyph
    quit
  value /= base
```

> Strength: unlimited values from one small BMP. The analog meter's trick: it stores **five color copies of the font stacked below the visible area of the same layer** and picks color by `srcY = 240 + color*60`. The window is only 240 tall, so rows below 240 are pure off-screen storage.

### Vector overlay (only the analog meter)
One element — the needle — is genuinely drawn, not blitted, using the CORDIC engine:
```spin2
x1 := qcos(190<<8, aval-1400, 3600)         ' tip X  (radius 190, angle from value)
y1 := qsin(190<<8, aval-1400, 3600)         ' tip Y
debug(`amp crop 1)                          ' wipe whole gauge (form a)
debug(`amp set `(160<<8, 225<<8))           ' pen to pivot
debug(`amp line `(x1+160<<8, y1+225<<8))    ' draw needle
debug(`amp crop 1 50 140 220 95)            ' restore hub patch over the messy pivot (form b)
```
Use this whenever an element is continuous (needle, trace, bar) rather than enumerable (digit, LED).

---

## 6. Image (BMP) file format — how to author the artwork

Every layer is a BMP file loaded by `LAYER n 'name.bmp'`. **Get the format exactly right or the layer won't load / won't look right.** All of the reference assets share one format; match it.

### Required format (verified from every asset in this project)
| Property | Value | Why |
|---|---|-----|
| Container | **Windows BMP** (`.bmp`) | The only format `LAYER` accepts. |
| Color depth | **24-bit RGB, 3 bytes/pixel** | All assets are 24-bit. |
| Alpha channel | **none** | 24-bit BMP has **no transparency** — see consequences below. |
| Compression | **none (BI_RGB, uncompressed)** | Plain pixel data. |
| Color space | sRGB, full color | Pixel value read back by `pc_mouse` as `$00_RR_GG_BB`. |

> The reference files happen to carry a 124-byte BITMAPV5 header (Photoshop/macOS "Save As BMP"); a plain 54-byte BITMAPINFOHEADER works too. What matters is **24-bit, uncompressed, no alpha.**

### The big consequence: NO transparency
Because there is no alpha, **every `CROP` copies an opaque rectangle** — it overwrites the destination completely. This drives the entire design discipline:

1. **Sprite cells must be self-contained.** Each glyph/state cell must already contain the correct background around the shape, because when you blit it, it replaces everything in that rectangle. (E.g. each digit cell includes its black readout-box background; each LED cell includes the surrounding gray bezel.)
2. **"Erasing" = copying clean background back** (CROP form b / a). There is no transparent paint. So your background layer must contain the pristine empty look of every region you'll later overwrite.
3. **Seams must match.** The pixels just outside a blitted cell come from the background; the pixels inside come from the sprite. For an invisible seam, **the cell's border pixels must match the background exactly** (same gray, same black box). Author sprites and background together, sampling the same colors.
4. **Pick a "blank" cell deliberately.** A font strip usually needs the empty/space cell to equal the readout background (so blanking a column = blit the blank cell, or re-crop background over it).

### Dimensions, grid, and layout
- **Author at exact device pixels.** No scaling happens; 1 BMP pixel = 1 window pixel. Decide the window `size W H` first, then draw to it.
- **Use a fixed cell pitch** so the index math is trivial: `srcX = index * cellWidth`. Keep cells edge-to-edge with no gaps (digits: 33, 44, or 45 px wide in the examples).
- **A layer may be larger than the window** and the extra area becomes free off-screen storage. The analog meter's layer is 495×540 inside a 320×240 window: the gauge occupies the top, and **five color copies of the digit font are stacked below y=240** purely as a palette. Use this to pack states/fonts into one layer.
- **Origin for CROP is top-left** of the image as you see it in an editor (the tool handles BMP's internal bottom-up row order). `srcY = 0` is the top row.

### Color & state encoding
- Encode a few discrete states as **whole-canvas BMPs, one per state** (Pattern A: off/red/green, switch up/down) and select with the layer number.
- Encode many values as a **horizontal strip of equal cells** (Pattern B: digit fonts) and select with `srcX = index*cellW`.
- Encode color variants either as **separate layers** or as **stacked rows in one layer** (`srcY = base + colorIndex*rowHeight`, the analog-meter approach).

### Authoring checklist for a new asset
1. Fix the window size; draw the background at that exact size; export 24-bit uncompressed BMP, no alpha.
2. For each variable element, decide Pattern A (state layers) or Pattern B (font strip), and lay cells on a uniform pitch.
3. Make each sprite cell include the matching background so blits leave no seam; make the background include the empty look so restores erase cleanly.
4. Note the exact cell width/height and each slot's destination (x,y) — those numbers go straight into your `CROP` calls.
5. Put the `.bmp` files **next to the `.spin2` source** (they're loaded by bare filename).

### Quick conversion / inspection
- Export from most editors as "BMP → 24-bit / R8G8B8, no compression."
- On macOS, convert anything to the right BMP with: `sips -s format bmp in.png --out out.bmp` (produces 24-bit BMP).
- Verify a file with: `file out.bmp` → expect `... x 24, ... ` (the `24` = 24-bit) and no compression.

---

## 7. Displays as INPUT devices (the switches example)

A graphical DEBUG window can read the **host PC's keyboard and mouse** back into the P2, so the picture becomes a control surface. Two commands do this; **each must be the LAST command in its `debug()` statement**, and the window must have focus.

### `PC_KEY(@key)` — keyboard
Writes one LONG. Returns the keypress from the last ~100 ms, else 0. Printable keys = ASCII (32–126); arrows/Home/End/etc. = small codes 1–13; Esc = 27.
```spin2
debug(`switches `pc_key(@key))              ' poll keyboard (LAST in statement)
if (key)
  case key
    "d","D": set_radix(10)
    "h","H": set_radix(16)
    "b","B": set_radix(2)
    " "    : reset_value()
```

### `PC_MOUSE(@xpos)` — mouse (7 consecutive longs)
Fills, in order: **`xpos, ypos, wheeldelta, lbutton, mbutton, rbutton, pixel`**.
- `xpos,ypos` — position in the window's coordinate basis; **both < 0 when the mouse is outside**.
- `wheeldelta` — momentary 0 / ±1.
- `lbutton/mbutton/rbutton` — **0 = up, -1 = pressed**.
- `pixel` — color under cursor `$00_RR_GG_BB`, or -1 outside.
```spin2
var long xpos, ypos, wheeldelta, lbutton, mbutton, rbutton, pixel   ' MUST be 7 consecutive longs
...
debug(`switches `pc_mouse(@xpos))           ' poll mouse (LAST in statement)
```

### Hit-testing: mapping a click to a control
The switches demo turns clicks into actions two ways:

1. **Named rectangular zone via a struct** (for the radix indicator):
   ```spin2
   con  struct rect(x1, y1, x2, y2)
   var  rect rtype
   ...
   rtype := 134, 81, 185, 106                ' the clickable zone (set in setup)
   ...
   if (lbutton) and in_zone(xpos, ypos, @rtype)
     next_radix()
   ```
   where `in_zone()` is a simple bounding-box test.

2. **Coordinate ranges via `case`** (for the 8 switches): one row band on Y, then an X `case` selects which switch:
   ```spin2
   if (lbutton) and (ypos => 129) and (ypos =< 179)
     case xpos
       265..285 : toggle_bit(0)
       232..252 : toggle_bit(1)
       ...
       034..064 : toggle_bit(7)
   ```
   `toggle_bit` flips the data bit and immediately blits the matching up/down switch sprite (Pattern A).

### The "dirty flag" loop (don't redraw every tick)
Interactive displays poll fast but only recompose/`update` when something changed:
```spin2
displayval, dirty := 0, true
repeat
  check_key()                                ' may set dirty
  check_mouse()                              ' may set dirty
  if (dirty)
    show_value(displayval, radix)            ' re-blit the readout
    debug(`switches update)                  ' single flip
    dirty := false
    waitms(250)
  waitms(100)
```

> Right-click and middle-click are used as shortcuts (next radix / reset). Button state is `-1` when pressed, so test `if (rbutton)`.

---

## 8. Decision guide for a NEW display

1. **List the elements** and classify each:
   - *Enumerable, few states* (LED on/off, switch up/down) → **Pattern A** whole-state layers, one BMP per state, `crop layer x y w h` (source=dest).
   - *Enumerable, many values* (digits, hex, letters) → **Pattern B** font strip, `srcX = index*cellW`, blit to a slot.
   - *Continuous* (needle, bar, trace) → **vector** (`set`/`line`/`dot`, often `precise`), then restore patches to clean up.
2. **Author the BMPs** to match your cell sizes. Keep background and (optionally) font in layers; remember you can stash extra glyph rows below the visible area (analog-meter trick).
3. **Choose a coordinate mode** (default vs `cartesian` vs `cartesian … precise`) and keep all coordinates consistent with it.
4. **Write `setup()`**: create window (`hidexy update`), load layers, `crop 1`, `update`.
5. **Write the update path**: compute → erase changed regions (form b) or repaint (form a) → blit new sprites (form c) → one `update`.
6. **If interactive:** add `pc_key`/`pc_mouse` polls (each LAST in its `debug()`), hit-test with bounding boxes or coordinate `case`s, and gate redraws behind a `dirty` flag.

---

## 9. Gotchas / rules of thumb

- `{Spin2_v50}` directive is mandatory for layer/crop.
- `CROP` argument order is **source rect, then destination**; the 4-number form copies to the same spot (erase), the 6-number form copies to `(x,y)` (blit).
- Nothing is visible until `UPDATE`; batch all crops, then one update — that is the no-flicker guarantee.
- There is no clear-screen — erase by re-cropping clean background.
- `pc_key`/`pc_mouse` must be the **last** command in their `debug()` statement and the window must have **focus**; key latch auto-clears after ~100 ms; mouse buttons read **-1** when down; mouse-outside gives negative coords.
- `pc_mouse` needs **7 consecutive longs**; declare them adjacently and pass the address of the first.
- Pick the coordinate mode first — a `y` value is meaningless without knowing default vs cartesian.
- Whole-state layers cost one full BMP per state; reserve for few-state elements. Font strips scale to unlimited values from one small BMP.

---

## 10. Per-file quick reference (copy-paste anchors)

**panel_010** — minimal output: 3 whole-panel layers, single same-spot crop per LED.
`img := value.[bit] + 1 + (ledcolor * value.[bit])` → `crop img x y 50 50`, step `x -= 50`.

**panel_digits** — output: panel off/on layers + 44×54 font strip (layer 3).
Blank box: `crop 1 108 53 372 106`. Digit: `crop 3 d*44 0 44 54 x1 53`. LED: `crop (bit+1) x y 50 50`.

**analog_meter** — output + vector: one packed sheet (bg + 5 color font rows at y=240..539, 45×60 cells).
Needle via `qcos/qsin` + `set`/`line`; digit: `crop 1 n*45 (240+color*60) 45 60 x1 161`; dp at sheet x=483.

**switches** — interactive: layers 1/2 = switch bank down/up (21×51 cells), 3 = hex font (33×50), 4 = radix labels `dhbo` (52×26), 5 = `radix_bits` underline (5-px rows).
Reads `pc_key` (d/h/b/o/space) and `pc_mouse` (zone + coordinate-range hit-tests); `dirty`-flag redraw.

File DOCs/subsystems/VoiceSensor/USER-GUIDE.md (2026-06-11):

# DF2301Q Voice Recognizer — Library User's Guide

A task-oriented manual for using the P2 (Spin2) driver for the DFRobot **DF2301Q "Gravity:
Offline Voice Recognition Sensor"** (SKU SEN0539) over I2C.

**Audience:** P2 application developers *and* AI coding agents integrating this object. It is
written to be read top-to-bottom by a human or consumed in pieces by an agent — every method has
a signature, a one-line contract, and a runnable snippet.

**How this fits the other docs** (read these for depth; this guide is the "how do I use it"):
- `DOCs/spec/P2-Gravity-Voice-Sensor-Specification.md` — the **formal API/behavior contract**.
- `DOCs/design/DRIVER-THEORY-OF-OPERATIONS.md` — **how the driver works inside**.
- `DOCs/reference/THEORY-OF-OPERATIONS.md` — the **device protocol** we ported from.
- `DOCs/COMMAND-CATALOG.md` — the **full built-in command-word list** (generated; machine-readable).

---

## 0. Minimal integration — the least you must add

**The question this section answers:** *what is the smallest set of files I drop into an existing
P2 system to make it respond to spoken commands?* Pick a tier and copy exactly those files.

| Tier | Add these files | You get |
|---|---|---|
| **Minimal** (react by ID) | `isp_voice_recognizer.spin2` **+** `isp_i2c_singleton.spin2` | poll `getCMDID()`, `case` on `voice.CMD_*` |
| **+ Phrases / custom words** | also `isp_voice_command_names.spin2` | `cmdName(id)` → text; register custom slots 5–21 |
| **+ Visual demo** | also `demo_voice_recognizer.spin2` + `panel_bg/font/hi.bmp` | the DEBUG-panel reference app |

**Recipe (minimal tier):**
1. Copy the two `.spin2` files next to your top-level object (pnut-ts resolves `OBJ` relative to
   the *including* file's directory).
2. Add the `OBJ` lines and call `start()` once, then poll — see [§2 Quick start](#2-quick-start).

**Shared-bus caveat:** `isp_i2c_singleton` is a *shared* I2C bus object. If your system already
includes it for another device, **reuse that instance** — do not add a second copy; the singleton
is meant to back every I2C device on the bus. You include it here only to bring up the bus and to
name the `i2c.PU_*` pull-up selectors.

> The integration-kit release zip (`Voice-Sensor-<version>.zip`) ships these files **flat**, plus
> this guide, the command catalog, and a worked `custom_words_example.spin2` — so it compiles in
> PNut as unpacked. The `demo` zip is the superset with the demo app and artwork.

---

## 1. What you get

A self-contained, **offline** speech-recognition peripheral exposed as a P2 object. The module
listens continuously, recognizes a spoken phrase from its ~150-word built-in vocabulary (plus up to
17 user-trained custom words), and reports the result to your application as a small integer
**command ID (CMDID)**. It can also speak reply audio and be configured (volume / mute / wake time).

Every bus method is **non-blocking**, so the driver can be polled from a shared "device scanner" cog
without stalling it.

### The object set (include what you need)

```
  your_app.spin2  / demo_voice_recognizer.spin2     your application / the demo
        |
        v
  isp_voice_recognizer.spin2     THE DRIVER — recognition, playback, config; CMD_* catalog
        |
        v
  isp_i2c_singleton.spin2        shared bit-banged I2C bus (one instance for all I2C devices)

  isp_voice_command_names.spin2  OPTIONAL — ID->phrase cmdName() + custom-word registration
```

- Need only to **react to commands**? Include `isp_voice_recognizer`; switch on its `CMD_*` constants.
- Need the **human phrase** (to print/display) or **custom words**? Also include
  `isp_voice_command_names`. It is opt-in so react-by-ID apps don't pay for the string table.

---

## 2. Quick start

```spin2
OBJ
    voice : "isp_voice_recognizer"
    i2c   : "isp_i2c_singleton"     ' only needed to reference the PU_* pull-up selectors

CON
    SCL_PIN = 18
    SDA_PIN = 16
    BUS_KHZ = 100                    ' 100 (standard) / 400 / 1000

PUB main() | id
    ' 1. Bring up the bus and confirm the sensor answers (PU_1K5 = strong internal pull-up;
    '    use i2c.PU_NONE if your board has external pull-ups).
    if not voice.start(SCL_PIN, SDA_PIN, BUS_KHZ, i2c.PU_1K5)
        debug("DF2301Q not found - check wiring")
        return
    voice.setWakeTime(15)            ' seconds awake after the wake word

    ' 2. Poll for recognitions (0 = nothing recognized).
    repeat
        id := voice.getCMDID()
        if id <> 0
            debug("heard CMDID ", udec_(id))
        waitms(50)                   ' >=50 ms between reads is enforced internally anyway
```

The interaction model on the device: the user says the wake word ("Hello Robot" by default), the
module wakes (blue LED), recognized command phrases each produce a CMDID for `WAKE_TIME` seconds,
then it sleeps until woken again.

---

## 3. Usage profiles

The driver supports three ways to be used over the same non-blocking primitives. Pick one.

| # | Profile | How | Read results with |
|---|---|-----|---|
| 1 | **Passive scanner-poll** (primary) | a foreign "scan all devices" cog calls in on each pass | `pollCMDID()` |
| 2 | **Self-poller cog** | `startPoller()` runs a dedicated cog into a mailbox | `getLatest()` |
| 3 | **Simple synchronous** | a foreground loop polls directly | `getCMDID()` |

**Bus-ownership rule (profile 2):** while the poller cog runs it **owns the bus**. Read only via
`getLatest()`, and configure `setVolume`/`setMuteMode`/`setWakeTime` **before** `startPoller()`. To
reconfigure later: `stopPoller()`, change settings, `startPoller()` again.

---

## 4. API reference — `isp_voice_recognizer` (the driver)

**Return convention:** *action* methods return a status **code** — `E_OK` (0) or `E_NAK` (-1, the
device did not acknowledge a bus byte). *Value* queries return their value (`0` from a CMDID read
means "nothing recognized," which is a value, not an error). *Presence* queries return `TRUE`/`FALSE`.

| Method | Returns | Purpose |
|---|---|---|
| `version()` | `pStr` | pointer to the version string (`"1.0.0"`) |
| `start(scl, sda, khz, pullup)` | `bFound` | init the bus on the pins, probe `$64`; seeds the volume shadow. `TRUE` if present. Call once first. |
| `getCMDID()` | `cmdId` | latest recognized ID, `0` = none (simple-profile alias of `pollCMDID`) |
| `pollCMDID()` | `cmdId` | latest recognized ID, `0` = none; non-blocking, >=50 ms read spacing enforced |
| `playByCMDID(cmdId)` | `status` | speak the reply audio for `cmdId` (fire-and-return; ~1 s plays async) |
| `isSpeaking()` | `bSpeaking` | `TRUE` while still inside the ~1 s window after `playByCMDID` |
| `enterWakeState()` | `status` | wake the module programmatically (via the play path) |
| `getWakeTime()` | `wakeSecs` | read the wake-up duration (seconds) |
| `setWakeTime(wakeSecs)` | `status` | set wake-up duration, 0..255 s |
| `setVolume(volLevel)` | `status` | set playback volume (passed through unclamped) and update the shadow |
| `getVolume()` | `volLevel` | current volume from the driver's **shadow** (the chip can't read it back) |
| `setMuteMode(muteOn)` | `status` | nonzero mutes, 0 unmutes |
| `startPoller()` | `ok` | profile 2: launch the poller cog. `TRUE` ok; `FALSE` if already running / no free cog |
| `stopPoller()` | — | profile 2: stop the poller cog, release the bus |
| `getLatest()` | `cmdId` | profile 2: non-blocking read of the poller mailbox, cleared on read |

**Useful constants:** `voice.CMD_*` (the full catalog — see §7), `voice.E_OK` / `voice.E_NAK`,
`voice.DEF_VOLUME`. The pull-up selectors passed to `start()` live on the I2C object
(`i2c.PU_NONE / PU_1K5 / PU_3K3 / PU_15K`) — include `isp_i2c_singleton` to name them, or pass the
numeric value.

---

## 5. API reference — `isp_voice_command_names` (optional phrases + custom words)

| Method | Returns | Purpose |
|---|---|---|
| `cmdName(cmdId)` | `pStr` | pointer to the human phrase: a built-in phrase, a **registered custom** phrase, `(custom)` for an unregistered custom slot, or `(unknown)` for an unmapped ID |
| `registerCustomTable(pTable)` | `status` | validate + register an app's custom-word table (see §6); `REG_OK` or a `REG_E_*` reason |
| `clearCustomWords()` | — | forget all registered custom phrases |

```spin2
OBJ
    voice : "isp_voice_recognizer"
    names : "isp_voice_command_names"

' ... in your loop ...
id := voice.getCMDID()
if id <> 0
    debug("heard: ", zstr_(names.cmdName(id)))   ' e.g. "Go Forward"
```

---

## 6. Custom words (the 17 user-trainable slots, IDs 5-21)

### How custom words work on the device
Custom words are trained **on the module, by voice** (the user speaks them during the module's own
learning workflow — see the product card / reference doc). The module then recognizes them and
reports their **slot ID (5-21)** — but it **stores no text**. So your **application is the only
place** that knows "slot 7 means 'good night'."

### On-device training & deletion (Gravity voice module cheat sheet)

You train and delete words **on the module itself, by voice**, using its built-in learning workflow.
Wake the module first (default wake word **"Hello Robot"**), then speak the control phrases below.

**Train a NEW WAKE WORD (greeting)**
1. Say: **"Hello Robot"**  (or the current wake word)
2. Say: **"Learning wake word"**
3. When prompted, repeat your NEW wake word 2-3 times

**Delete the WAKE WORD**
1. Say: **"Hello Robot"**
2. Say: **"I want to delete"**
3. When the menu plays, say: **"Delete wake word"**
4. Confirm when it asks (e.g. say **"Yes"**)

**Train a NEW COMMAND WORD**
1. Say: **"Hello Robot"**
2. Say: **"Learning command word"**
3. When prompted, repeat the NEW command 2-3 times

**Delete ONE COMMAND WORD**
1. Say: **"Hello Robot"**
2. Say: **"I want to delete"**
3. When the menu plays, say: **"Delete a command word"**
4. Follow its prompts to choose which word & confirm

**Delete ALL learned COMMAND WORDS**
1. Say: **"Hello Robot"**
2. Say: **"I want to delete"**
3. When the menu plays, say: **"Delete all commands"**
4. Confirm when it asks (e.g. say **"Yes"**)

> **Notes**
> - **17 custom command words max** (slots 5-21), plus the built-ins.
> - Only **one** custom wake word at a time.
> - **Train a whole set in ONE uninterrupted session.** Interrupting and resuming corrupts the module's
>   sequential slot assignment — words added after a break may silently fail to commit and then mis-recognize
>   onto earlier slots (observed on this hardware 2026-06-10). Before training a fresh set, say
>   **"Delete all commands"** to clear the old ones, then train straight through without stopping.

### How to program the dog's command set (the working 17)

This is the robot's trained vocabulary. Program these 17 words **on the device, in this exact order**, and
the shipped firmware (`robot_dog_top`'s `dogVocab` + `voiceToDogCmd()`) recognizes them with **no code
changes** — verified on hardware 2026-06-11 (catalog run, clean 1:1).

Each row shows **two numbers on purpose:**
- **Train #** — the count the module prompts you with as you add words (1st word, 2nd word, …). Use it to
  **track which word you're on** while training.
- **CMDID** — the slot ID the module assigns (5..21) and reports to the firmware. This is what the code maps.

Because the module assigns slots **in training order**, training in this order makes Train # *N* land on
**CMDID = N + 4** — that's the whole table:

| Train # | CMDID | Say this word | Dog does |
|---:|---:|---|---|
| 1  | 5  | **Stand** | ease to a neutral stand |
| 2  | 6  | **Sit** | sit (rear lowered) |
| 3  | 7  | **Lie Down** | low flat rest |
| 4  | 8  | **Crouch** | low symmetric crouch |
| 5  | 9  | **Relax** | tucked resting pose |
| 6  | 10 | **Take a Bow**  | play bow (front low, rear up) |
| 7  | 11 | **Forward** | walk forward |
| 8  | 12 | **Backward** | walk backward |
| 9  | 13 | **Turn Left** | turn left in place |
| 10 | 14 | **Turn Right**  | turn right in place |
| 11 | 15 | **Halt** | stop, hold a stand |
| 12 | 16 | **Say Hi** | one-shot wave |
| 13 | 17 | **Shake** | sit + offer a paw (shake) |
| 14 | 18 | **Salute** | raise a paw to a salute |
| 15 | 19 | **Push Ups** | flex down/up a few times |
| 16 | 20 | **Nod Yes** | nod the head "yes" |
| 17 | 21 | **Parade Rest** | parade-rest posture |

**Steps:**
1. **Delete all commands** first (see the cheat sheet above) so slots start fresh at 5.
2. Train the 17 above **in order, in ONE uninterrupted session** (don't stop to do anything else — a break
   corrupts the slot assignment).
3. Verify with `src/test_voice_map.spin2` (catalog mode): say each word, "Read Compass" to advance; the
   SUMMARY should read a clean **5 → 21**, every word distinct. Run it twice and diff — identical = trusted.

**Built-in aliases (already in the code):** the factory words **"Go Forward"** (CMDID 22) and **"Retreat"**
(CMDID 23) also drive **Forward** and **Backward** — they're always recognized, so either the custom word
or the built-in works. See `DOCs/subsystems/VoiceSensor/VOICE-COMMAND-MAP.md` (the authoritative map).

### Telling the library what your custom words mean
Declare your custom vocabulary as an **inline table** in your DAT and register it once. Each entry is
**one index byte** (the custom slot) followed immediately by a **zero-terminated phrase**; a single
`0` byte ends the table. Phrases are variable length and may be multi-word.

```spin2
DAT ' ---- my application's custom voice words ----
myCustomWords
            byte    5, "open the garage door", 0     ' CMD_CUSTOM_1
            byte    6, "turn on the shop lights", 0  ' CMD_CUSTOM_2
            byte    7, "good night", 0               ' CMD_CUSTOM_3
            byte    0                                 ' end of table

PUB setup() | status
    status := names.registerCustomTable(@myCustomWords)
    if status <> names.REG_OK
        debug("custom table rejected: ", sdec_(status))
```

After a successful register, `cmdName(7)` returns `"good night"` and any display that already calls
`cmdName()` shows the real phrase automatically — **no display code changes needed**.

### Why inline (not a table of pointers)
The strings live **inside** the table on purpose. A table of `@phrase` pointers built in your DAT
would store **object-relative** offsets that this object cannot resolve (different object base). The
inline form needs only the single absolute `@myCustomWords` you pass — see §9 for the `@`/`@@` detail.

### `registerCustomTable` is a one-time validator
It walks your table once and **registers nothing unless the whole table is valid** (all-or-nothing),
returning a reason code:

| Code | Meaning |
|---|---|
| `REG_OK` (0) | table validated and registered |
| `REG_E_INDEX` (-1) | an index byte is outside the custom range (5-21) |
| `REG_E_UNTERMINATED` (-2) | a phrase had no `0` within `CUSTOM_MAXLEN` (63) bytes |
| `REG_E_TOO_MANY` (-3) | more than `CUSTOM_COUNT` (17) entries |
| `REG_E_DUP` (-4) | the same custom index appears twice |

Storage note: the library keeps only a small pointer per slot (`CUSTOM_COUNT` longs); your strings
stay in your DAT (permanent), so nothing is copied and nothing dangles.

---

## 7. The built-in command catalog

The full ID->phrase list (≈150 commands) is in **[`DOCs/COMMAND-CATALOG.md`](COMMAND-CATALOG.md)** —
generated from `tools/cmdname_catalog.tsv`, so it never drifts from the code. React by ID using the
`voice.CMD_*` constants:

```spin2
case voice.getCMDID()
    voice.CMD_GO_FORWARD: ...     ' ID 22
    voice.CMD_RETREAT:    ...     ' ID 23
```

Custom slots are IDs 5-21 (`CMD_CUSTOM_1`..`CMD_CUSTOM_17`). **Validate IDs against the printed
command-word card for your firmware revision** — revisions have reshuffled lists.

---

## 8. DEBUG, timing, and troubleshooting

**DEBUG channels** (compile-time, zero overhead when off): set `DEBUG_MASK = (1 << DBG_I2C)` in
`isp_i2c_singleton` to trace bus bytes (channel 0), or `DEBUG_MASK = (1 << DBG_VOICE)` in
`isp_voice_recognizer` to trace recognitions/config (channel 1), then rebuild.

**Timing guarantees:** no `waitms` in any bus method; `>=50 ms` between actual CMDID reads is enforced
by a tick check (a too-soon poll returns the cached value); `playByCMDID` is fire-and-return with the
~1 s window exposed via `isSpeaking()`.

**Troubleshooting:**
- `start()` returns `FALSE` → wiring/address/pull-up. On a bare bench use `i2c.PU_1K5` (the weaker
  `PU_3K3` can idle the bus low).
- Reads always return 0 → ensure clock-stretching is intact in the I2C layer (the DF2301Q holds SCL
  low while preparing data; the singleton waits for it — do not remove that).
- `cmdName()` shows `(custom)` for a trained word → your app hasn't called `registerCustomTable`, or
  it returned a `REG_E_*` reason (check the return value).

---

## 9. For maintainers

**`@` vs `@@` (the addressing rule this object depends on):**
- In a **DAT** block, `@label` is an **object-relative** offset.
- In a **PUB/PRI** body, `@label` is an **absolute** hub address at runtime.
- To use a DAT-stored offset at runtime, convert with `@@` (`@@table[i]`).
The generated phrase table stores relative WORD offsets and reads them with `@@`; the custom-word
table is walked from the single absolute pointer the app passes, so no `@@` is needed there.

**Regenerating the phrase table / catalog** (source of truth = `tools/cmdname_catalog.tsv`):
- `python3 tools/gen_cmdname_table.py --apply` — re-splice `cmdName()` + the DAT table into
  `src/isp_voice_command_names.spin2` (between the `>>> GENERATED` markers).
- `python3 tools/gen_cmdname_table.py --catalog-md` — regenerate `DOCs/COMMAND-CATALOG.md`.
Edit the `.tsv`, run both; never hand-edit the generated regions.

---

## 10. Related documents

- `DOCs/spec/P2-Gravity-Voice-Sensor-Specification.md` — formal contract
- `DOCs/design/DRIVER-THEORY-OF-OPERATIONS.md` — internal design
- `DOCs/reference/THEORY-OF-OPERATIONS.md` — device protocol (I2C + UART), findings F1-F7
- `DOCs/COMMAND-CATALOG.md` — full built-in command-word list (generated)

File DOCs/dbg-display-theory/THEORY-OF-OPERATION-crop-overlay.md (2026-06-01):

# Theory of Operation — The "Crop & Overlay" Display Technique

**Subject file:** `jm_debug_analog_meter_050.spin2` (Jon "JonnyMac" McPhalen)
**Companion file:** `jm_debug_panel_digits_020.spin2`
**Platform:** Parallax Propeller 2, Spin2 `DEBUG(\`PLOT ...)` display, requires `{SPIN2_V50}` or later.

---

## 1. What problem is being solved

The author wants a *photo-realistic instrument panel* — an analog needle gauge with a 4-digit numeric readout — drawn inside a P2 `DEBUG` PLOT window, updated many times per second, with **no flicker** and **no per-pixel drawing code** on the P2.

Drawing such a panel pixel-by-pixel every frame would be slow, would flicker, and would require a font renderer and artwork routines on the microcontroller. The "crop & overlay" technique sidesteps all of that: **all the artwork is pre-drawn into BMP files**, loaded once into off-screen *layer buffers* inside the PLOT window, and each frame is composed by **copying ("cropping") small rectangles out of those buffers onto the visible canvas.** The P2 never draws art — it only issues copy commands with coordinates.

This is exactly the classic video-game **sprite-sheet / blitting** model, implemented entirely through three V50 PLOT sub-commands: `LAYER`, `CROP`, and `UPDATE`.

---

## 2. The three primitives (authoritative semantics)

From the P2 Knowledge Base (`DEBUG PLOT`, V50 layer commands):

### `LAYER`
```
DEBUG(`name LAYER n 'file.bmp')
```
Loads a BMP file into off-screen **layer buffer `n`** (1–8). The layers are private image stores attached to the window; nothing about loading a layer changes the visible canvas. Up to 8 layers persist until replaced or the window closes.

### `CROP` — has three forms
```
DEBUG(`name CROP n)                              ' (a) whole-layer restore
DEBUG(`name CROP n left top width height)        ' (b) copy region onto SAME spot
DEBUG(`name CROP n left top width height x y)     ' (c) copy region to (x,y)
```
- **(a)** copies the *entire* layer `n` to the canvas origin — i.e. repaints the whole background. Used to initialize the scene and to wipe it.
- **(b)** copies a rectangle from layer `n` back to the **identical** coordinates on the canvas. This is the **"erase"** operation — it restores a patch of pristine background over whatever was drawn there last frame.
- **(c)** copies a `width×height` rectangle whose top-left in the layer is `(left,top)` to **destination `(x,y)`** on the canvas. This is the **"blit a sprite"** operation — the workhorse of the technique.

> Note the argument order: **source rect first (`left top width height`), destination last (`x y`)**. This is the single most common point of confusion when reading the code.

### `UPDATE`
```
DEBUG(`name UPDATE)
```
The window is created with the `HIDEXY UPDATE` options, which puts it in **manual / double-buffered mode**: nothing the P2 draws becomes visible until an explicit `UPDATE`. All the `CROP`s for a frame are issued first, then one `UPDATE` flips them onto the screen at once. **This is what makes the animation flicker-free** — the user never sees a half-composed frame.

---

## 3. The artwork (sprite sheets)

The technique lives or dies on how the BMP files are laid out. The meter uses a single, cleverly-packed sheet.

### `debug_analog_meter_050.bmp` — 495 × 540 px, loaded as **layer 1**

It is one image containing everything:

| Region | Y range | Contents |
|---|---|---|
| **Meter face** | 0 – 239 | The full panel artwork: bezel, arced scale (1–9), "P2 DEBUG" watermark, and an *empty* black 7-segment readout box. This is the background. |
| **Digit font, 5 rows** | 240 – 539 | Five horizontal strips of 7-segment digits `0`–`9`, one strip per color. Each strip is 60 px tall; each digit cell is **45 px wide × 60 px tall**. A decimal-point glyph sits at the right end (≈ x=483). |

The five color rows map directly to the enum in the code:
```
#0, RED, GREEN, BLUE, YELLOW, WHITE     ' row index 0..4
```
so a digit's vertical position in the sheet is selected purely by color:
```
y2 := 240 + (DIG_CLR * 60)              ' DIG_CLR = WHITE = 4  ->  y2 = 480
```

The genius here: **the visible background and the font live in the same layer buffer.** The portion below the gauge (y ≥ 240) is never shown to the user — it's an off-screen palette the code samples from. The window itself is only 320 × 240; everything from y=240 down is "below the fold," used as storage only.

### Companion sheets for the digits panel
`jm_debug_panel_digits_020.spin2` splits the same idea across multiple layers:
- **layer 1** `panel_leds_off.bmp` (480×240) — background with 8 dark LEDs and an empty display box.
- **layer 2** `panel_leds_on.bmp` — identical panel but with the 8 LEDs lit green.
- **layer 3** `panel_digits.bmp` (484×54) — a single horizontal strip: digits `0`–`9` then a minus sign, each cell **44 px wide × 54 px tall**.

Here the two LED states are *whole alternate backgrounds*; an individual LED is updated by cropping the matching 50×50 patch out of whichever layer holds the desired state.

---

## 4. Frame lifecycle — the analog meter

### 4.1 One-time setup (`setup()`)
```spin2
debug(`plot amp title 'Analog Meter+' size 320 240 pos 650 200 hidexy update)
debug(`amp cartesian 1 0 precise)        ' Y-up coordinate system, sub-pixel needle
debug(`amp color red linesize $400)       ' needle = red, 4.0-px wide (×256 in precise mode)
debug(`amp layer 1 'debug_analog_meter_050.bmp')  ' load the sheet off-screen
debug(`amp crop 1)                         ' paint full background (form a)
debug(`amp update)                          ' show it
```
After this the window shows the empty gauge. The font strips are sitting in layer 1, unseen.

### 4.2 Per-update (`update_meter(aval, dval, dpbits, force)`)

**Arguments:** `aval` = needle value 0–1000; `dval` = number to show 0–9999; `dpbits` = 4-bit mask of which decimal points to light; `force` = 4-bit mask of which digit columns to show even when they'd be a leading zero.

**Step A — compute and draw the needle (vector, not sprite).**
```spin2
x1 := qcos(190<<8, aval-1400, 3600)        ' CORDIC: needle tip X
y1 := qsin(190<<8, aval-1400, 3600)        ' CORDIC: needle tip Y
debug(`amp crop 1)                          ' (a) wipe whole canvas back to clean gauge
debug(`amp set `(160<<8, 225<<8))           ' move pen to needle pivot
debug(`amp line `(x1+160<<8, y1+225<<8))    ' draw needle to computed tip
```
The needle is the *one* element drawn live, using the P2 **CORDIC** engine (`qcos`/`qsin`) to convert the gauge value into an angle and project the tip. Radius is 190, pivot is (160,225), the `<<8` is the 8-bit fixed-point that `precise` mode expects. `aval-1400` and span `3600` set the zero-point and sweep of the dial.

**Step B — tidy the pivot.**
```spin2
debug(`amp crop 1 50 140 220 95)            ' (b) restore a patch over the needle's base
```
The line is drawn from the exact pivot, which would leave an ugly hub. Re-cropping the clean background rectangle (50,140)–(270,235) over the base hides the messy origin so the needle appears to emerge cleanly from behind the bezel.

**Step C — render the 4-digit readout (sprite blitting).**
```spin2
y2 := 240 + (DIG_CLR * 60)                  ' pick the color strip in the sheet
d  := 1000                                   ' most-significant divisor
repeat c from 3 to 0                          ' columns left -> right
  n := v / d                                  ' the digit value 0..9
  if (dval >= d) || force.[c]                 ' suppress leading zeros unless forced
    x1 := 70 + ((3 - c) * 45)                 ' on-screen column position (45 px apart)
    debug(`amp crop 1 `(n*45, y2, 45, 60, x1, 161))   ' (c) blit digit glyph
    if (dpbits.[c])
      x1 += 33
      debug(`amp crop 1 `(483, y2+49, 8, 8, x1, 210))  ' (c) blit a decimal point
  v //= d
  d /= 10
```
For each of the four columns the code:
1. extracts the digit `n`,
2. computes the **source X** in the sheet as `n*45` (digit's cell) at **source Y** `y2` (its color strip),
3. computes the **destination X** on screen, and
4. issues form-(c) `CROP` to stamp that 45×60 glyph into the readout box.
Optional decimal points are stamped from a small 8×8 glyph at sheet x=483.

Because each digit is just a rectangle copy, "rendering a font" costs the P2 nothing but arithmetic — there is no glyph rasterizer.

**Step D — present the frame.**
```spin2
debug(`amp update)                           ' flip everything to screen at once
```
Everything composed in Steps A–C was invisible until this single `UPDATE`. The viewer sees the new needle position and new number appear together, atomically — no flicker.

### 4.3 The driving loop (`main()`)
```spin2
repeat
  update_meter(0, 0, %0010, %0011)           ' rest at 000.0
  waitms(500)
  repeat level from 0_0 to 100_0 step 5      ' sweep 0 -> 100.0
    update_meter(level, level, %0010, %0011)
    waitms(50)
  waitms(1000)
```
`%0011` forces the two right-most columns to always show (so the display reads `00.0` rather than blank), and `%0010` lights the decimal point in column 1, giving a fixed `NN.N` format.

---

## 5. Why it works — the underlying model

```
   BMP file on host  ──LAYER──▶  off-screen layer buffer (in the PLOT window)
                                          │
                                          │  CROP (copy rectangles)
                                          ▼
                                  off-screen canvas  ──UPDATE──▶  visible window
```

1. **Art is data, not code.** All pixels are authored in an image editor and shipped as BMPs. The P2 firmware contains zero artwork — only coordinates and copy commands. Changing the look means editing a BMP, not the program.
2. **The layer is both background *and* sprite atlas.** One image holds the scene plus a font/state palette below the visible area. "Drawing a digit" = "copy from the palette region." "Erasing" = "copy from the background region."
3. **Erase-by-restore, not erase-by-clear.** There is no clear-to-black; you paint the pristine background back over the dirty region (form a for the whole scene, form b for a patch). This guarantees the restored pixels exactly match the surrounding art.
4. **Double-buffering gives atomic, flicker-free frames.** `HIDEXY UPDATE` defers display; the many `CROP`s for a frame land all at once on `UPDATE`.
5. **Work is offloaded to dedicated silicon.** The needle angle uses the CORDIC (`qcos`/`qsin`); the blits are handled by the debug display host. The Spin2 code is just a thin sequencer of coordinates.

The result is a smooth, attractive instrument rendered by a microcontroller that, strictly speaking, never draws a gauge — it only says *"copy this rectangle to there, then show it."*

---

## 6. Quick reference — coordinate cheat sheet (analog meter)

| Element | Source in layer 1 (l, t, w, h) | Destination (x, y) |
|---|---|---|
| Full background | whole image (form a) | 0, 0 |
| Needle-base wipe | 50, 140, 220, 95 (form b) | same spot |
| Digit `n`, color `C` | `n*45`, `240+C*60`, 45, 60 | `70+(3-c)*45`, 161 |
| Decimal point | 483, `240+C*60+49`, 8, 8 | digit_x+33, 210 |

Window: 320×240. Needle pivot: (160,225), radius 190, drawn in `precise` (×256) coordinates. Visible art occupies y=0–239; the digit font palette occupies y=240–539 off-screen.

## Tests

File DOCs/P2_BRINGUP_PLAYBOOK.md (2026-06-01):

# P2 Bring-Up Playbook

A bench checklist for proving each Robot Dog (FNK0050) subsystem **one at a time** on the
P2, driven by the `src/isp_dog_bringup.spin2` menu console. Run top to bottom — the order is
dependency-first (bus before the chips that ride it, sensors before actuators).

- **Firmware build:** `src/isp_dog_bringup.spin2`, version **0.1.0** (`FW_VERSION_*` in
  `src/isp_version.spin2`).
- **Target:** the **P2 bench unit** — one P2 Edge on the adapter plate, **battery connected**
  (the board regulates 5 V → 3.3 V from the pack; do not power the P2 from USB alone for the
  servo tests), USB serial to the **programming port**.
- **Terminal:** **2 Mbaud (2,000,000)**, 8-N-1 — the project standard for all P2 comms. Each
  exercise names its **menu digit** in its heading — type it to run that test.
- **Est. run time:** ~20-30 min.

> **Conventions.** Authored to the `test-playbook` skill and this project's
> `.claude/skills/test-playbook/project-overlay.md`. This is the project's **standing**
> bring-up playbook (cross-referenced from `../src/README.md` and
> `P2_FIRMWARE_THEORY_OF_OPS.md`), so it keeps this descriptive name rather than the per-sprint
> `<NAME>-TEST-PLAYBOOK.md` pattern under `DOCs/plans/`. With no sprint plan yet, each exercise's
> **Verifies** cites the driver object and the README's ⚠-verify items in place of a plan
> section / `«#N»` task.

> **SAFETY — read before exercises 8-10.** Those move servos. **Lift and support the robot**
> so the legs hang free first. P2 over-voltage: the HC-SR04 **ECHO** (5 V, exercise 7) reaches
> **P9 through a ~1 kΩ inline series resistor** (the P2 pin clamps it to VIO, ≤ 10 mA); the
> WS2812 data is 3.3 V into a 5 V part (usually fine). See `P2_MIGRATION_WIRING.md` §4.

> **⚠ verify items.** Some constants were inferred, not metered. **Resolved 2026-06-01:** the
> battery divider is **÷3, not ÷2** (ex. 3 — metered 7.68 V → reads 7.76 V). The **leg↔channel
> map is verified** (ex. 8–10, 2026-06-01). **Still inferred:** the WS2812 **strip variant** (ex. 6
> — bit timing matches `jm_rgbx_pixel`; only WS2812 350/700 vs WS2812B 400/800 ns remains), and the
> joint **side-mirror + CORDIC IK** (ex. 10, validate through motion). Where an exercise proves one
> of these, it is marked **⚠**; record the measured reality in the notes.

---

## Bring-up results — 2026-06-01 (non-motion interfaces)

First pass done **not** via the menu console below but with per-interface **auto-run** top files
(`src/test_*.spin2`) that emit P2 `DEBUG()` at 2 Mbaud and exit on `TEST_DONE` — driven headless:
`pnut-ts -d -q src/test_X.spin2` then `pnut-term-ts -r src/test_X.bin -b 2000000 --headless
--end-marker "TEST_DONE"`. **The `-b 2000000` is required** (headless does not auto-apply the debug
baud to the runtime read; without it the 2 Mbaud DEBUG is garbage). Logs land in `logs/`.

| Ex. | Interface | Result | Finding |
|---|---|---|---|
| 1 | Serial / DEBUG console | ✅ | DEBUG @ 2 Mbaud clean once `-b 2000000` passed. |
| 2 | I²C bus scan | ✅ | 0x40, 0x48, 0x68 (+0x70 PCA9685 all-call). 3.3 V rail + `PU_1K5` confirmed. |
| 3 | Battery | ✅ FIXED | Divider is **÷3** (was ÷2); 7.68 V metered → 7.76 V read. |
| 4 | IMU | ✅ | Accel `az≈+1 g`, gyro `<0.25 deg/s` at rest after **hardened** `calibrateGyro` (motion-reject). |
| 5 | Buzzer | ✅ | Audible **only with the Load/servo rail ON** (buzzer is on the Load rail). |
| 6 | LED ring | ✅ | R/G/B (GRB) + rainbow, 7 px. |
| 7 | Ultrasonic | ✅ | Tracks motion; **~1 kΩ series R into P9 fitted** (5 V echo via pin clamp). Load on. |
| 8–10 | Servos / legs / head | ✅ | **PCA9685 wake bug fixed** (MODE1 SLEEP never cleared → no PWM); all 13 servos center & hold. **Leg map verified**: FL=4/3/2, BL=7/6/5, BR=8/9/10, FR=11/12/13, head=15. FL/BR toes need a small tibia trim (calibration). |

---

## 0. Setup (once)

- **Action:** Build and flash `src/isp_dog_bringup.spin2` (`pnut-ts -q src/isp_dog_bringup.spin2`,
  then load to RAM/FLASH). Open the serial terminal at 2 Mbaud (2,000,000).
- **Expected:** The banner `=== Robot Dog (P2) bring-up console ===` and the numbered menu
  appear, ending with `> `.
- **Pass/fail:** `[ ]`

---

## 1. Serial console  — *implicit*

- **Verifies:** `isp_serial_singleton` on the programming port; clock config (`_clkfreq`).
- **Targets:** 1 P2, no peripherals.
- **Setup:** Exercise 0 complete.
- **Action:** Observe the menu; press any unmapped key (e.g. `0`).
- **Expected:** Menu renders cleanly (no garbage = correct baud/clock); unmapped key prints
  `? unknown choice` and the menu redraws.
- **Pass/fail:** `[ ]`

## 2. I²C bus scan  — menu `1`

- **Verifies:** I²C master (`isp_i2c_singleton`), the **3.3 V rail restored onto header pins
  1/17**, and the **P2-supplied pull-ups (`PU_1K5`)** — the board has none (#1 migration gotcha).
  Detects PCA9685 / ADS7830 / MPU6050. (Requires the bus set up with `PU_1K5`, not `PU_NONE`.)
- **Targets:** 1 P2 + connection board powered from the battery.
- **Setup:** Battery connected; nothing lifted needed.
- **Action:** Press `1`.
- **Expected:** `found 0x40`, `found 0x48`, `found 0x68` and `3 device(s)`. Missing any one
  ⇒ stop and check the 3.3 V rail / SDA-SCL wiring before going further (every later I²C test
  depends on this).
- **Pass/fail:** `[ ]`   Found: ______________________

## 3. Battery  — menu `2`  ⚠

- **Verifies:** `isp_battery_monitor` → `isp_i2c_ads7830`; ADC read, median, ÷2 divider, cutoff.
- **Targets:** 1 P2 + battery.
- **Setup:** Note the pack voltage from a multimeter for comparison.
- **Action:** Press `2`.
- **Expected:** `battery: NNNN mV (N.N V)` within ~±0.3 V of the metered pack voltage.
  Low-pack warns below 6.4 V.
- **⚠ verify:** if the reading is off by a constant factor, the VREF (5000 mV) or divider
  (×2) constant in `isp_i2c_ads7830` / `isp_battery_monitor` is wrong — record metered vs read.
- **Pass/fail:** `[ ]`   Metered ____ V / Read ____ V

## 4. IMU  — menu `3` (live)

- **Verifies:** `isp_imu` → `isp_i2c_mpu6050`; wake, ranges, accel/gyro burst read, gyro
  calibration, accel tilt (CORDIC).
- **Targets:** 1 P2 + battery; robot sitting still on the bench.
- **Setup:** Hold the robot **level and still** while it prints "calibrating".
- **Action:** Press `3`. Watch the stream. Tilt the body by hand. Press any key to stop.
- **Expected:** At rest, `az` ≈ +1000 mg (gravity), `ax`/`ay` near 0, gyro near 0 mdps after
  calibration. Tilting forward/back changes `tilt p`; rolling changes `tilt r`, sign
  consistent with the tilt direction.
- **Pass/fail:** `[ ]`   Rest az ____ mg / tilt tracks? ____

## 5. Buzzer  — menu `4`

- **Verifies:** `isp_buzzer` on P10.
- **Targets:** 1 P2.
- **Setup:** none.
- **Action:** Press `4`.
- **Expected:** Three audible ~150 ms beeps.
- **Pass/fail:** `[ ]`

## 6. LED ring  — menu `5` (live)  ⚠

- **Verifies:** `isp_led_ring` → `isp_ws2812` on P8; GRB framing, brightness, modes,
  WS2812 bit timing.
- **Targets:** 1 P2 + 7-pixel strip.
- **Setup:** none (a level shifter on the data line is recommended).
- **Action:** Press `5`. Observe solid **red**, then **green**, then **blue**, then a moving
  rainbow. Press any key to stop (ring goes off).
- **Expected:** Correct colors in the right order (proves GRB byte order) on all 7 pixels;
  smooth rainbow (proves timing). Wrong colors per pixel ⇒ wire-order constant; flicker/wrong
  hues ⇒ **⚠** WS2812 timing constants vs `datasheet/WS2812.pdf`.
- **Pass/fail:** `[ ]`   Color order OK? ____ Rainbow stable? ____

## 7. Ultrasonic  — menu `6` (live)

- **Verifies:** `isp_hcsr04` on TRIG P11 / ECHO P9; trigger pulse + echo timing + mm conversion.
- **Targets:** 1 P2 + HC-SR04. ECHO is **5 V, undivided** (metered 2026-05-31) → **~1 kΩ series
  resistor into P9** (P2 pin clamps to VIO, ≤ 10 mA); no divider.
- **Setup:** ⚠️ The ultrasonic is on the **Load/servo rail** — turn the **Load switch ON** to
  power it (the logic-only "legs-off" mode won't), so **support the robot** for this test.
  Confirm the ~1 kΩ series R is in line to P9 before connecting.
- **Action:** Press `6`. Move a hand/target to known distances (e.g. 100 mm, 300 mm). Press a
  key to stop.
- **Expected:** Distance tracks the target within ~±10 mm; `-- no echo --` when pointed at
  open space beyond range.
- **Pass/fail:** `[ ]`   @100mm reads ____ / @300mm reads ____

## 8. Servo controller + head center  — menu `7`  *(MOVES)*

- **Verifies:** `isp_i2c_pca9685` start/configure (PWM freq) and a single servo write via
  `isp_head` (ch 15).
- **Targets:** 1 P2 + battery + PCA9685 + head servo.
- **Setup:** **LIFT/SUPPORT THE ROBOT.** Battery connected (servos need pack current).
- **Action:** Press `7`.
- **Expected:** PCA9685 config debug prints; the head servo moves to/holds center (~90°),
  no buzzing/stall.
- **Pass/fail:** `[ ]`

## 9. Head pan sweep  — menu `8`  *(MOVES)*

- **Verifies:** `isp_head` `sweep` across its travel limits and re-center.
- **Targets:** as exercise 8.
- **Setup:** Controller already up (or this test brings it up); robot supported.
- **Action:** Press `8`.
- **Expected:** Head pans smoothly min→max, then back to center; stays within ~50-130° (no
  mechanical binding at the ends).
- **Pass/fail:** `[ ]`

## 10. One leg (front-left)  — menu `9`  *(MOVES)*  ⚠

- **Verifies:** `isp_leg` channel map + side mirror (`setJointAngles`) and the **CORDIC inverse
  kinematics** (`moveToXYZ`), plus the leg↔channel↔side assignment.
- **Targets:** 1 P2 + battery + PCA9685 + the front-left leg's 3 servos.
- **Setup:** **ROBOT LIFTED/SUPPORTED**, front-left leg free to move.
- **Action:** Press `9`. Watch: direct mid pose → IK neutral `(0,99,10)` → reach `(20,90,10)`
  → back to neutral.
- **Expected:** The **front-left** leg (and only it) moves; the three joints move in sane
  directions; the IK poses look like a leg reaching/lifting, not slamming to a limit.
- **⚠ verify:** if a *different* leg moves, the channel/side map is wrong (README §3). If
  joints move backwards or jam at 0/180°, the IK scaling/quadrant or the femur/tibia mirror is
  wrong — record which joints and directions.
- **Pass/fail:** `[ ]`   Correct leg? ____ Sane motion? ____

---

## Integration milestones (beyond the standalone console)

Exercises 1-10 prove each driver **standalone** in the bring-up console's own cog. The
production firmware runs them under two resource-owner service cogs plus a comms cog (see
`P2_FIRMWARE_THEORY_OF_OPS.md`), so integration is **staged** — prove all of 1-10 green first.

### Stage I — discrete-pin IO cog (`isp_io_controller`)

- **Verifies:** one cog owns LED + buzzer + ultrasonic, served non-blocking via mailbox B.
  Exercises **5 (buzzer)**, **6 (LED)**, **7 (ultrasonic)** are its per-driver prerequisites.
  Note ex. 7 tests the *blocking* ranging path; the IO cog uses the **non-blocking smart-pin**
  path (`startSmart`/`firePing`/`echoReadyMm`, `P_HIGH_TICKS`), first proven *here*.
- **Setup:** a small top harness that `cogspin`s `isp_io_controller` and posts to mailbox B
  via `postCommand` (**TODO** — analogous to the bring-up console). Robot supported as usual.
- **Action / Expected:** post `IO_RANGE_ON` **+** an animated `IO_LED_MODE` **+** an
  `IO_BUZZ_BEEP` together. The rainbow animates **smoothly while** `getDistanceMm()` updates
  stream and a beep fires — **no hitching** in any of the three. The ~210 µs LED frame must not
  disturb ranging; a beep must not freeze the animation. (Per D7: smart-pin timing → ~1 % cog
  load → no jitter.)
- **Pass/fail:** `[ ]`  concurrent LED + range + beep clean? ____

### Stage II — backend body-control cog (`isp_robot_dog`)

Motion + IMU/battery sensing under cooperative tasks on the **I²C-owning** cog, driven via
mailbox A. Do **not** run gaits until single-leg motion (ex. 10) is validated.

### Stage III — full robot

Both service cogs + the comms cog wired together (`cogspin` of backend + IO + the comms loop);
teleop via mailboxes A/B; gaits, poses, gestures. The top-level cog launch is the remaining
build step. See `P2_FIRMWARE_THEORY_OF_OPS.md`.

---

*Record results inline (`[x]` pass, note failures). A failed exercise is a finding: fix the
driver and re-run, or log it as outstanding work. Companion docs: `../src/README.md`
(object/pin inventory), `P2_MIGRATION_WIRING.md` (authoritative wiring), `HARDWARE_SETUP.md`.*

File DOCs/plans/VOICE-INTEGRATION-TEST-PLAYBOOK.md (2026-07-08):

# VOICE-INTEGRATION — Bench Verification Playbook

> ⚠ **Historical (plumbing-phase) artifact.** This playbook was written when the `voiceToDogCmd()` seam
> deliberately returned `CMD_NONE` for every word and Exercise 5 used a *throwaway* mapping that had to be
> reverted. The **CMDID→behavior map has since been completed** and is wired live (custom slots 5–21 +
> built-in aliases 22/23) — so the "no spoken word moves the dog" / "mandatory revert to `CMD_NONE`"
> instructions below are **superseded**. For current behavior see
> [`../subsystems/VoiceSensor/VOICE-COMMAND-MAP.md`](../subsystems/VoiceSensor/VOICE-COMMAND-MAP.md) and
> the Theory of Operations §2/§5. The wiring/observability exercises (0–4, 6) still stand.

**Build:** 0.3.0 · **Targets:** 1 P2 bench unit (DF2301Q voice on the 2nd I²C bus, P18 SCL / P16 SDA)
— plus the host (no robot) for Exercise 0, and a **multimeter** for Exercise 1. **Est. run time:**
~45–60 min.

This is the on-hardware proof for the **voice-recognizer wiring-in** sprint (VOICE-INTEGRATION,
plan §7 `«#26»`). The sprint is **plumbing + observability only** — it proves *we hear commands over
I²C and which CMDIDs arrive*, and that the new bus/cog/dispatch plumbing coexists with everything
already shipped. **Voice CMDID → behavior mapping is the NEXT sprint**; the `voiceToDogCmd()` seam
returns `CMD_NONE` for every word, so in normal builds **no spoken word moves the dog**. Exercise 5
*temporarily* wires a throwaway mapping to exercise the dispatch+gating path end-to-end, then reverts.

Each exercise is tagged so you know what it's for:

- **[NEW]** — verify new voice behavior shipped this sprint (recognition, telemetry, dispatch/gating).
- **[CERT]** — certify a previously-trusted subsystem still works now that cog 2 owns a 2nd bus and
  cog 0 is a dispatch loop (bus-1 motion/IMU/battery, ranging, LED).
- **[ELEC]** — bus-2 electrical is already **resolved** (pull-up `PU_1K5`; supply 3.3 V metered) —
  Exercise 1 is record-only, wiring §3a.

> Record pass/fail on each exercise — `sprint-closeout` reads these. A failed exercise is a finding:
> fix it before closeout, or (exception) carry it to `DOCs/plans/PUNCH-LIST.md`. If a run surfaces
> several wrong behaviors, **record them all first**, then hand the set to `defect-fixing` as one
> symptom inventory — they often share a root cause.

---

## What's new this build — what to look (and listen) for

- **A 2nd I²C bus now exists** on P18/P16, owned by the **IO cog** (cog 2), carrying the DF2301Q.
  Bus 1 (servos/IMU/battery on P13/P15, cog 1) is untouched — the two buses must not interfere.
- **The IO cog publishes recognized CMDIDs** as latest-wins telemetry (`getVoiceCmdId()` /
  `getVoiceSeq()`), exactly like it publishes ranging (`distMm` / `pingSeq`).
- **cog 0 (`robot_dog_top`) is now a persistent dispatch loop**, not a scripted demo. It watches the
  voice telemetry and *would* hand commands to the backend — but the map seam yields `CMD_NONE`, so
  it only **traces** its dispatch+gating decisions this sprint.
- **Feedback you can sense:** the DF2301Q **speaks its own verbal acknowledgement** (vendor firmware,
  free), and the firmware adds a **single green LED-ring blink** on each recognition. (The full
  spinning-green / red-refused / off-idle scheme is documented as the mapping sprint's target.)

---

## Driver map & run pattern

| Exercise | Driver | Build | End-marker | Timeout | Robot? |
|---|---|---|---|---|---|
| 0 Automated gate | compile sweep (`BUILD_COMMAND`) | — | — | — | no (host) |
| 1 Bus-2 electrical | RESOLVED — record-only (pull-up `PU_1K5`, supply 3.3 V) | — | — | — | no |
| 2 Bus-2 recognition | `test_voice.spin2` | `test_voice` | *(none — runs to timeout)* | 120 | no (dog unpowered/safe) |
| 3 Bus coexistence | `robot_dog_top.spin2` (clean) | `robot_dog_top` | *(none — dispatch loop)* | 90 | yes |
| 4 Absent-module degradation | `robot_dog_top.spin2` (clean) | `robot_dog_top` | *(none — dispatch loop)* | 60 | yes |
| 5 Dispatch + gating (throwaway map) | `robot_dog_top.spin2` (**temp mapping**) | `robot_dog_top` | *(none — dispatch loop)* | 120 | yes |

Flash/run pattern (all P2 comms at **2 Mbaud**). The voice harness and the dispatch loop are
**persistent** — they run until the harness `--timeout`, with **no end-marker**:

```bash
pnut-ts -d -q src/<driver>.spin2
pnut-term-ts -r src/<driver>.bin -b 2000000 --headless --timeout <N>
```

---

## Exercise 0 — Automated compile-sweep GATE (run before any hardware step) [CERT]

- **Verifies:** §7 `«#26»` — every `.spin2` object still compiles after the sprint diff (swapped
  voice OBJ §1, the IO-cog voice telemetry + green blink §2/§5, the reshaped `robot_dog_top` dispatch
  loop §3, and the new `test_voice.spin2` §4). This is the cheap gate: if it's red, **fix the code
  before spending bench time.**
- **Targets:** host only, no robot.
- **Action:**
  ```bash
  cd "$(git rev-parse --show-toplevel)"
  rc=0; for f in src/*.spin2; do pnut-ts -q "$f" || rc=1; done; rm -f src/*.bin; echo "rc=$rc"
  ```
- **Expected:** **45/45 GREEN** (the 44-object baseline + the new `test_voice.spin2`). The four
  untouched IO-cog test tops (`test_dog_gaits/level/tricks/stand/panel`) and `custom_words_example`
  still compile.
- **PASS TELL:** `rc=0`, every file reports `Wrote …` with no error.
- **Pass/fail:** `[x]`  45/45 green? **YES — 45/45, 2026-06-10** (re-confirmed after the `cmdName` `@@` fix).

---

## Exercise 1 — Bus-2 electrical: RESOLVED (no action) [ELEC]

> **Both bus-2 electrical items are closed — no bench action required.**
> - **Pull-up:** `VOICE_I2C_PULLUP = PU_1K5`, matching the bench-proven working driver (vendor
>   quick-start + `custom_words_example` both call `i2c.PU_1K5`; `PU_3K3` idled the bus low).
> - **Supply rail:** **3.3 V** (metered 2026-06-10) → SDA/SCL idle ≈ 3.3 V, within the P2's range,
>   **no clamp/level-shift needed.**
>
> Kept here for the record; wiring §3a is the authoritative source. Proceed to Exercise 2.

---

## Exercise 2 — Bus-2 recognition: "do we hear commands, and which CMDIDs?" [NEW]

- **Verifies:** §4 `«#23»` (the primary observability gate) + §5 `«#22»` (green blink). **The headline
  exercise of the sprint.** Depends on Ex 0 green (bus-2 electrical already resolved, Ex 1).
- **Targets:** 1 bench unit, **dog unpowered / unsupported is fine** — only the IO cog runs; no
  servos, no IMU, no backend. Safe to run on the desk.
- **Driver:** `test_voice.spin2` (timeout 120, no end-marker — speak during the window).
- **Setup:** module wired + powered (Ex 1). Flash `test_voice`; watch the banner.
- **OBSERVE (console):**
  - Banner prints: driver version, `voice bus = SCL P18 / SDA P16 (DF2301Q @ I2C $64)`, and
    **`voice present = T`**, then `LISTENING`.
  - Speak the DF2301Q **wake word** (e.g. "Hello Robot"), then a handful of **built-in command words**
    from `DOCs/subsystems/VoiceSensor/COMMAND-CATALOG.md` — e.g. **"Go Forward" (CMDID 22)**,
    **"Retreat" (23)**, **"Turn Left 90 Degrees" (25)**. Each should print
    `heard #N: CMDID <id>  '<phrase>'` with the **correct catalog ID + phrase**.
  - Say something **not** in the vocabulary → **nothing prints** (CMDID 0 is never published).
- **PASS TELL (all four):**
  1. banner shows **`voice present = T`**;
  2. each spoken built-in word prints its **correct CMDID + phrase**;
  3. an unrecognized utterance prints **nothing**;
  4. you **hear the module's own verbal ACK** and see **one green LED-ring blink** per recognition.
- **If FAIL:** `voice present = F` → re-check Ex 1 wiring/pull-up/rail; wrong/absent IDs → confirm the
  module's command-word card matches the catalog; no blink → check the WS2812 (LED is on the IO cog).
- **Bench result 2026-06-10** (`src/logs/debug_260610-114927.log` + earlier runs):
  - **`voice present = T`** — module ACKs on bus 2 at `$64`. **PASS.**
  - **Recognition works** — real built-in IDs arrived: **CMDID 2** (Hello Robot / wake) and **CMDID 22**
    (Go Forward). The IO-cog telemetry (`getVoiceSeq`/`getVoiceCmdId`) + 0→nonzero edge-detect are
    proven. **PASS (numeric IDs).**
  - **Phrase display** — initially `zstr_(names.cmdName(cmdId))` dumped the (zero-free) name-offset
    table as binary, and a `$1B` byte in it tripped `DEBUG_END_SESSION`, ending the capture early
    (looked like a premature timeout). **Root cause:** `cmdName` used the bare `@@nmTbl_0[i]` form,
    which under pnut-ts returned the table-entry address instead of resolving the stored offset.
    **Fixed** → explicit `@@WORD[@nmTbl_0][i]` idiom (`isp_voice_command_names.spin2`).
    **CONFIRMED on hardware** (`src/logs/debug_260610-120132.log`): 10 recognitions, every CMDID→phrase
    pair correct vs `COMMAND-CATALOG.md`, spanning all three tables — CMDID **2** `Hello Robot`
    (`nmTbl_0`), **22/23/24** `Go Forward`/`Retreat`/`Park A Car` (`nmTbl_22`), and
    **36/39/42/48/68** `Face Recognition`/`Line Tracking`/`Object Sorting`/`Load Model`/`Read Compass`
    (`nmTbl_29`). Clean run, no binary, full duration. **PASS.**
  - **Green LED blink** — came **on at the first recognition but stayed solid** (did not self-clear /
    re-blink). **FINDING → carries to the LED-feedback work** (see below); the imperative blink in
    `stepVoice` races the LED animator. Not blocking recognition.
- **Pass/fail:** `[x]`  present=T? **YES** · correct CMDIDs+phrases? **YES — 10/10 correct vs catalog,
  3 tables (log 120132)** · unknown prints nothing? **not yet exercised** · verbal ACK? **___** ·
  green blink? **DEFECT (stuck on) — see LED-feedback note**

---

## Exercise 3 — Bus coexistence: full robot, both buses live [CERT] [NEW]

- **Verifies:** §7 `«#26»` — with the **full `robot_dog_top` build**, bus 1 (servos/IMU/battery) is
  **unaffected** by bus-2 voice traffic; two independent buses, two owner cogs. Depends on Ex 2.
- **Targets:** 1 bench unit, full 3-cog shape, all 13 servos, IMU, battery, **Load ON**, voice module
  wired.
- **Driver:** `robot_dog_top.spin2` (clean, `DEMO_ON_BOOT = FALSE` — the default dispatch loop;
  timeout 90).
- **Setup:** **support the robot** during gyro-cal + first rise; then set down level.
- **OBSERVE:**
  - **[CERT]** Boot proceeds normally: IO cog up (green "alive" + hello chirp), backend inits,
    **gyro-cals, and STANDS** in the loaded-rear crouch — exactly as build 0.2.0. Banner reports
    **`voice present = T`**.
  - **[CERT]** Telemetry sane while voice is being spoken at the module: battery mV reads, the dog
    holds its stand (no servo glitching), and if you exercise ranging/LED via the panel build they
    still work. (Bus-1 traffic doesn't stall.)
  - **[NEW]** Speaking built-in words still logs `voice: CMDID <id> '<phrase>'` from the dispatch loop
    **while the dog stands** — recognitions register concurrently with a live bus-1 backend.
  - **[NEW]** Each recognition traces a **gate line** (`gate: dogCmd=0 mode=… → …`) and
    **`no behavior mapped (CMD_NONE); nothing posted`** — confirming the dog **does not move** on voice
    this sprint.
- **PASS TELL:** the dog **inits/cal/stands normally AND voice recognitions log concurrently**, with
  no servo disturbance and **no motion triggered** by speech.
- **Bench result 2026-06-10** (`src/logs/debug_260610-120703.log`):
  - 3-cog runtime up (IO cog1, backend cog2); gyro cal succeeded after 6 motion-retries (expected
    while hand-supported), `bias x=239 y=-248 z=-23`; **initial STAND reached** — all feet
    `tgt(55,78,±10)=cur`, `mode=3`, `tilt p=-1 r=0` (level); `battery 7704 mV`. **`voice present = T`**
    on bus 2 *with the full bus-1 backend live* — coexistence proven.
  - Three recognitions during the stand, phrases correct (fix holds in the full build): CMDID **2**
    `Hello Robot`, **22** `Go Forward`, **23** `Retreat`. Each traced
    `gate: … moveDone=1 busy=0 halted=0 -> HANDOFF` then `no behavior mapped (CMD_NONE); nothing posted`
    — **no motion on speech**. **PASS.**
  - Minor notes (non-blocking): (a) banner labels cogs `cog1 backend | cog2 IO`, but runtime launched
    **IO=cog1 / backend=cog2** — cosmetic label vs dynamic cog assignment → punch-list nit;
    (b) ranging idle (`dist=-1 mm pingSeq=0`) — out of Ex 3 scope, confirm separately.
- **Pass/fail:** `[x]`  normal stand? **YES** · voice logs while standing? **YES (2/22/23)** · no servo
  glitch / no motion on speech? **YES (CMD_NONE, nothing posted)** · *(visual: green-alive/chirp = eyeball)*

---

## Exercise 4 — Absent-module degradation: quiet orchestrator, no hang [NEW]

- **Verifies:** §7 `«#26»` — with the voice module **unplugged**, `robot_dog_top` runs as a quiet
  orchestrator: no hang on the missing bus, all other subsystems normal. Reuses Ex 3's clean build.
- **Targets:** 1 bench unit, full 3-cog shape, **voice module unplugged** (or power its bus off).
- **Driver:** `robot_dog_top.spin2` (same clean build as Ex 3; timeout 60).
- **Setup:** physically **disconnect the DF2301Q** from P18/P16; support the robot for cal + rise.
- **OBSERVE:**
  - Boot reaches **`voice present = F`** (the start() probe NAKs; the bounded clock-stretch guard means
    **no stuck bus**).
  - The dog still **inits, gyro-cals, and stands** normally; the dispatch loop runs **silently** (no
    voice lines — `getVoiceSeq()` never advances) and **never hangs**.
- **PASS TELL:** `voice present = F`, normal stand, dispatch loop idles cleanly for the whole window —
  **no freeze, no servo fault.**
- **Bench result 2026-06-10** — two disconnect cases run:
  - **All voice pins disconnected** (`src/logs/debug_260610-121854.log`): **`voice present = F`** —
    correct. Normal 3-cog boot, gyro cal (`bias x=243 y=-248 z=-28`), **STAND reached** (`tilt p=-1 r=0`,
    `battery 7704 mV`), dispatch loop idle, clean session end — **no hang.** **PASS.**
  - **3.3 V supply removed but SDA/SCL + GND still wired** (`src/logs/debug_260610-121417.log`):
    **`voice present = T` — FALSE POSITIVE.** The probe is `i2c.present(DEV_WR)`, an address-ACK only
    (`isp_voice_recognizer.spin2:278`). With the `PU_1K5` pull-ups + GND connected, the unpowered
    DF2301Q is **parasitically powered through its I/O clamp diodes** and still ACKs `$64`. So
    **`present = T` means "something ACKs at `$64`", NOT "the module is powered + functional."**
- **FINDING → probe hardening: IMPLEMENTED.** `start()` now follows the address-ACK with a **liveness
  check** — `probeLive()` writes two distinct values to `REG_WAKE_TIME ($06)` and requires each to read
  back exactly (original restored). A phantom-powered chip ACKs but cannot store+return register data.
  - **Bench-confirmed 2026-06-10 — both directions, finding CLOSED:**
    - 3.3 V lifted / phantom-powered (`src/logs/debug_260610-124713.log`): the state that previously read
      `T` now reads **`voice present = F`** — false positive eliminated.
    - 3.3 V reconnected / powered (`src/logs/debug_260610-124838.log`): **`voice present = T`**, and
      recognition unaffected (CMDID 2/22/23 correct) — the liveness check is not over-strict and the
      `REG_WAKE_TIME` round-trip + restore does not disturb operation. **PASS.**
- **Pass/fail:** `[x]`  present=F (all pins off)? **YES** · normal stand? **YES** · no hang, quiet idle?
  **YES** · *(note: power-only-off gives a false present=T — probe-hardening finding above)*

---

## Exercise 5 — Dispatch + motion-gating, end-to-end (TEMPORARY throwaway mapping) [NEW]

> ⚠ This is the **only** exercise where a spoken word moves the dog, and it uses a **throwaway test
> mapping that MUST be reverted before closeout.** Real word→behavior mapping is the next sprint.

- **Verifies:** §3 `«#24»` — the dispatch loop + motion-gating skeleton work end-to-end: a one-shot
  blocks the next handoff until `getMoveComplete()`, a latched gait is interruptible, and `isHalted()`
  suppresses handoff. Depends on Ex 3.
- **Targets:** 1 bench unit, full 3-cog shape, all servos, IMU, battery, Load ON, voice wired.
  **Keep the dog supported** — it will move on command.
- **Setup — apply the throwaway mapping** in `src/robot_dog_top.spin2`, replacing the body of
  `voiceToDogCmd()`. Mark it unmistakably temporary:
  ```spin2
  PRI voiceToDogCmd(voiceCmdId) : dogCmd
  ' >>> THROWAWAY BENCH MAPPING -- §7 Ex 5 ONLY -- REVERT TO `dogCmd := dog.CMD_NONE` BEFORE CLOSEOUT <<<
      dogCmd := dog.CMD_NONE
      case voiceCmdId
          23: dogCmd := dog.CMD_NOD        ' "Retreat"            -> one-shot (gating: blocks next handoff)
          22: dogCmd := dog.CMD_FORWARD    ' "Go Forward"         -> latched gait (interruptible)
          24: dogCmd := dog.CMD_STOP       ' "Park A Car"         -> stop / supersede
  ```
  Recompile (`pnut-ts -d -q src/robot_dog_top.spin2`) and flash (timeout 120).
- **Action / OBSERVE:**
  1. **One-shot blocks next handoff** — say **"Retreat"** (→ `CMD_NOD`). The dog nods; **immediately**
     say "Retreat" again. The 2nd command's gate line shows **`busy`/`moveDone=0` → withhold** (held)
     until the nod completes (`getMoveComplete()` TRUE), then it hands off. *One-shots don't stomp each
     other mid-move.*
  2. **Latched gait is interruptible** — say **"Go Forward"** (→ `CMD_FORWARD`, latched). The dog walks.
     Say **"Park A Car"** (→ `CMD_STOP`) → the gate **allows the supersede** and the gait eases to a
     stop. *A new command interrupts a latched gait.*
  3. **(If feasible) halt suppresses** — on a low/critical battery, `isHalted()` latches: gate lines
     show **`halted=1 → withhold`** and **nothing posts**. (Skip if you can't safely reach the floor.)
- **PASS TELL:** the three gating behaviors are observable in the **gate trace + the dog's motion**:
  one-shot holds, gait interrupts, (halt suppresses).
- **MANDATORY REVERT:** restore `voiceToDogCmd()` to `dogCmd := dog.CMD_NONE` (drop the `case`),
  recompile, and confirm Ex 0 is green again. **Log the revert** so closeout sees the throwaway gone.
- **Pass/fail:** `[ ]`  one-shot holds? ___ · gait interruptible? ___ · halt suppresses (or n/a)? ___ ·
  **throwaway mapping REVERTED + recompiled?** ___

---

## Closeout inputs

- **Per-exercise pass/fail** above → `sprint-closeout` verification state.
- **Bus-2 electrical** → fully resolved (pull-up `PU_1K5`; supply 3.3 V metered 2026-06-10),
  recorded in wiring §3a. No open electrical items.
- **Ex 5 revert confirmation** → the throwaway mapping must be gone (Ex 0 green) before the sprint closes.
- **Open findings → `DOCs/plans/PUNCH-LIST.md`:**
  - **Voice probe hardening** (Ex 4) — DONE + fully bench-verified both directions: address-ACK +
    `REG_WAKE_TIME` write/read-back liveness check. Phantom (3.3 V-lifted) → `F`, powered → `T` with
    recognition intact. No longer an open finding.
  - **Green-blink stuck-on** (Ex 2) — RESOLVED by the new LED engine (`isp_led_engine`: single owner of
    the ring; cues are single-shot overlays that revert to the base). Bench-verified 2026-06-10 via
    `test_led_engine` (`src/logs/debug_260610-124917.log`): 4 recognition-style green cues each flash and
    revert to OFF — no stuck-on. (Also added a slower, readable chase/wipe pace and a `RAINBOW_BREATHE`
    mode.) The live voice cue now routes through `led.blink()` on the same engine path.
  - **Cog-label banner nit** (Ex 3) — fixed in `robot_dog_top` (now `cog1 IO | cog2 backend`).
- Any failure not fixed in-sprint → new active item in `DOCs/plans/PUNCH-LIST.md`.

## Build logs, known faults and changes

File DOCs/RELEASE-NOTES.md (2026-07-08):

# P2 Robot Dog — Release Notes

User-facing summary of each firmware build. Newest at the top.

---

## 0.3.0 — 2026-06-11

Adds the **Voice Integration** work — the dog now has a name and a spoken command source — plus a
rebuilt LED system. The recognizer and its command map are bench-confirmed; the live "speak a word,
watch the dog do it" run is the next bench step.

**The dog can now be commanded by voice**

- **Say "Hello Peabody," then a command.** The dog is named **Peabody**. A DFRobot DF2301Q offline
  voice module (a P2-only addition, on its own 2nd I²C bus — no cloud, no network) listens for the wake
  phrase and then a command word.
- **A 17-word vocabulary, one word per action:** Stand, Sit, Lie Down, Crouch, Relax, Take a Bow,
  Forward, Backward, Turn Left, Turn Right, Halt, Say Hi, Shake, Salute, Push Ups, Nod Yes, Parade Rest.
  Each recognized word is mapped to the matching motion and handed to the body — held if the dog is
  mid-gesture, allowed to interrupt a walk, and refused if the battery has cut out.
- **Two spare "factory" words** — "Go Forward" and "Retreat" — are accepted as extra triggers for
  Forward and Backward, covering the times the recognizer mishears those two rhyming words.
- **How the vocabulary is trained matters:** all 17 words must be trained in **one uninterrupted
  session** — pausing partway silently corrupts the module's slot assignment. (This was learned the
  hard way; the user guide now spells it out.)

**A rebuilt LED ring**

- The ring is now driven by a single **LED engine** — one owner, no more flicker from competing
  writers. It offers sustained looks (off / solid / color-wipe / theater-chase / rainbow / rainbow-cycle
  / a new **breathing rainbow** throb) plus brief one-shot **cues** that flash and return to whatever
  was showing. A short **green blink** now acknowledges each recognized voice command.

**Confirmed on the bench**

- The recognizer is **present-checked** so a powered-off-but-wired module can't fool the firmware into
  thinking voice is live. All 17 words trained cleanly and were cataloged as a clean 1:1 map.

**Known / not yet done**

- The **live end-to-end voice→motion demo** — the dog actually performing each spoken command through
  the full path — has not yet been run on the bench. That's the headline next step.
- The **full LED feedback scheme** (spinning green = acting, red = refused, off = idle) is designed and
  now easy to wire, but only the basic green recognition blink is hooked up so far.

---

## 0.2.0 — 2026-06-09

Closes the **Dog-Like-Motion-01 Keystone** sprint — the dog's resting stance was rebuilt so poses and
walking all grow from one consistent shape, and the bench pass that proved it fixed two things that
looked wrong.

**The new resting stance**

- **A natural "loaded" crouch.** At rest the dog now settles into a single, consistent stance — the
  hindquarters carry a bit more and tuck slightly back, the front stands a touch taller — and every
  pose and gait now eases to and from that same shape instead of a flat, square box. Measured on the
  bench, it stands **level**.

**What works now that didn't before**

- **Salute.** The dog now **salutes standing at attention** instead of from a sit — it shifts its
  weight, raises the front-right paw, holds, and lowers, all without tipping over. (Before, the salute
  could tip toward the raised paw.)
- **Shake** still offers its paw from a seated position, and settles back level when done.
- **Lie down.** Reworked into a clean **low, flat rest** — the dog sits low and level with its paws
  flat on the ground (the earlier version tilted nose-up and lifted the front paws off the floor).
  Bench-verified level. A noticeably *lower* (belly-down) lie-down is limited by one front leg's
  calibration and is parked for a future leg re-trim.
- **Walking.** Each leg keeps its own foot height while walking, so the rear stays lower than the front
  through the whole gait instead of flattening out mid-stride. All six gaits and the speed control run
  smoothly and ease cleanly to a stop.

**Confirmed on the bench**

- The tilt sensor's **left/right direction** was verified by hand-tilting the dog — leaning left reads
  positive, as intended. Combined with the earlier front/back check, both tilt axes are now trusted.
- The resting stance measures **level**, so no leveling trim is applied.

**Naming**

- The integrated demo program was renamed from `isp_robot_dog_top` to **`robot_dog_top`** so the
  top-level app is clearly distinct from the internal building-block modules.

**Known / not yet verified**

- A noticeably *lower* lie-down (belly near the floor) is limited by one front leg's calibration and
  would need that leg re-trimmed — parked as a separate bench task.

---

## 0.1.2 — 2026-06-08

First tagged build. Closes the **Bench-Repairs-01** sprint — a round of fixes to how the dog poses,
gestures, and protects itself, all verified on the bench.

**What works now that didn't before**

- **Bow.** The dog now lifts its head as it bows, so the snout clears the surface instead of dipping
  into it — and when it stands back up, the head returns to wherever you had it pointed before the bow.
- **Shake & salute.** Before lifting the front-right paw, the dog shifts its weight onto the other three
  legs so it no longer tips. When the trick finishes, it settles back to a level, centered sit instead
  of staying leaned over.
- **Hello / wave.** The waving foot now floats clearly above the floor through the whole wave — it no
  longer scuffs the ground at the bottom of each swing.
- **LED ring.** The solid / wipe / chase color modes now light up from a fresh power-on (they default
  to white) instead of looking dead until a color was sent. The control panel also shows which LED mode
  is active by name.

**New protection**

- **Low-battery safety.** A new hard cutoff: if the pack drops below 5 V (confirmed over several quick
  re-reads so a momentary dip won't trip it), the dog announces "battery too low," eases gently down to
  rest, and refuses further movement until it's powered off and back on. The earlier "getting low"
  warning at 6.4 V still works as a softer advisory. Verified on a genuinely flat pack.

**Behind the scenes (affects what you see in logs)**

- The bench tilt readings are now taken after the body has fully settled, so the numbers reflect the
  final pose rather than a mid-motion blur.
- A tilt-sensor axis labeling error was corrected — "pitch" now means front/back tilt and "roll" means
  left/right tilt, as you'd expect.

**Known / not yet verified**

- The left/right tilt **sign** (which way counts as positive) hasn't been confirmed yet — it needs a
  deliberate left/right tilt test, planned for the next sprint.
- The dog still stands with a few degrees of residual lean; squaring that up is the focus of the next
  ("dog-like motion") sprint.

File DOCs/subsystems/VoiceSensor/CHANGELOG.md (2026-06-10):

# Changelog

Notable changes to the P2 DF2301Q Voice Sensor driver. Entry style follows
`DOCs/policy/changelog-style-guide.md`.

This file is the **version of record**: the top version here must match the driver's internal
`version()` string (`DRIVER_VERSION` in `src/isp_voice_recognizer.spin2`) **and** the git tag
(`vX.Y.Z`). The release workflow refuses to publish if any of the three drift.

## v1.0.0 (2026-06-10)

**First public release of the I2C voice-recognition driver.**

### New Features
- `getCMDID()` / `pollCMDID()`: Non-blocking poll for the recognized command ID
- `playByCMDID()`: Play the module's reply audio for a command ID
- `setVolume()` / `setMuteMode()` / `setWakeTime()`: Configure playback and wake duration
- Three usage profiles: scanner-poll, self-poller cog (`startPoller`/`getLatest`), synchronous
- `cmdName()`: ID→phrase lookup via the optional `isp_voice_command_names` object
- `registerCustomTable()`: Register an application's custom words for slots 5–21
- `CMD_*` constants for the full built-in command-word vocabulary

### Tests
- `cmdName()` custom-table round-trip test

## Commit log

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2026-05-31 Add robot-dog hero image to README
    Use the kit image (currently with the stock Raspberry Pi on top); to be
    swapped for the P2 board once mounted.
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2026-05-31 Commit P2 pin mapping: signals on P8–P15, far-end→VCC order
    Replace the placeholder P0–P5 suggestion with the decided assignment:
    ECHO→P8, TRIG→P9, Buzzer→P10, LED→P11, SCL→P14, SDA→P15 (P12–P13 spare).
    Ordered to mirror the robot connector physically for minimal crossover —
    P8 at the far end, the I²C pair at the VCC end. Documented in the wiring
    map §3 and summarized in CLAUDE.md.
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2026-05-31 Electrical certification + as-built P2 pin map
    Bench cert (2026-05-31, batteries-out for resistance):
    - 5 V rail present (hdr 2/4); grounds common (6/9/14)
    - 3.3 V rail absent (Pi gone); pins 1/17 read ~5 V but rails are 30+ MOhm
    (not bridged) -> harmless leakage, MPU6050 safe
    - No board I2C pull-ups (the Pi's own ~1.8k left with it) -> P2 must supply
    them; SDA has a real ~6.9 kOhm pull-down -> use PU_1K5 (PU_3K3 would fail)
    - HC-SR04 ECHO = 5 V, undivided -> ~1 kOhm inline series resistor into P9
    (P2 pin clamps to VIO, <=10 mA per datasheet); ultrasonic on the Load/servo rail
    - Finding: battery-in/switches-off leaves an always-on path -> standby drain
    As-built adapter pin map (verifi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
2026-06-01 Apply PU_1K5 I2C pull-ups (board has none; SDA pull-down)
    The connection board has no I2C pull-ups (the Pi's left with it) and SDA carries
    a ~6.9 kOhm pull-down, so the P2 must drive a strong pull-up. Use PU_1K5 (SDA
    idles ~2.71 V, valid high; PU_3K3 would be ~2.2 V and fail).
    - isp_i2c_ads7830, isp_i2c_mpu6050, bring-up console scan: setup with PU_1K5
    - seed isp_i2c_pca9685: PU_NONE overridden to PU_1K5 via a Spin2 OBJ CON
    override at the call site (no seed edit -- keeps it backport-clean), so the
    PCA9685 uses PU_1K5 during its own present/config transactions
    - backed out the after-config re-assert (insufficient; the seed does I2C inside start())
    Makes all console I2C exercises (scan/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
2026-06-01 P2 bring-up: non-motion interfaces verified; battery ÷3 fix; gyro cal hardened
    Bench bring-up 2026-06-01 (P2 on adapter, battery powered) proved each
    non-motion interface in isolation via new per-interface test_*.spin2 harnesses
    (P2 DEBUG @ 2 Mbaud, run headless: pnut-term-ts -b 2000000 --end-marker).
    Verified: I2C bus (0x40/0x48/0x68 +0x70 all-call), WS2812 LED ring (P8),
    buzzer (P10, on the Load rail), ultrasonic (TRIG P11/ECHO P9, ~1k series R),
    IMU accel/tilt, battery ADC.
    Fixes & hardening:
    - isp_battery_monitor: DIVIDER_RATIO 2 -> 3 (metered 7.68 V pack -> 7.76 V read);
    Freenove's x2 is wrong for this v1.0 board.
    - isp_imu calibrateGyro: settle + paced sampling + peak-to-peak moti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
2026-06-01 PCA9685 wake-from-sleep fix: servos now drive; leg map verified
    Servo turn-on bring-up 2026-06-01 (robot lifted). The PCA9685 ACKed and
    "configured" but no servo moved: setPWMFrequency() never cleared the MODE1
    SLEEP bit in its wake step --
    (old_mode & !(MODE1_SLEEP & MODE1_RESTART) | MODE1_AUTOINCREMENT_ENABLE)
    MODE1_SLEEP & MODE1_RESTART ANDs two distinct bits ($10 & $80 = 0), so
    !(...) is all-ones and the mask is a no-op: the chip powers up asleep
    (MODE1=0x11) and stays asleep -> no PWM. Fixed by masking OFF both bits:
    (old_mode & !(MODE1_SLEEP | MODE1_RESTART) | MODE1_AUTOINCREMENT_ENABLE)
    With that, all 13 servos energize and hold at center (90 deg / 1500 us).
    Verified on hardw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
2026-06-02 Backend cog drives motion through the real path; central-driver fixes
    Pivoted from bespoke direct-drive harnesses to testing through the production
    backend cog (isp_robot_dog) so every motion exercises the real IO path. This
    surfaced and fixed several central-driver bugs the harnesses had hidden:
    - isp_i2c_pca9685: default PULL_UP_PCA9685_I2C PU_NONE -> PU_1K5. The CON-override
    used by top files compiled a SEPARATE controller instance from the one the servo
    objects hold internally; that instance was never configured, so servo-path writes
    went nowhere. Making PU_1K5 the default lets the whole stack share one configured
    controller (no override needed).
    - isp_leg: per-instance state (b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
2026-06-02 Confirm init stand commands the correct folded stance; cleanup
    Diagnostic readback proved the init standPose commands the correct folded angles
    (FL coxa/femur/tibia = 61/115/88, FR = 84/24/72) -- identical to CMD_STAND. So the
    IK + mirror + calibration are correct at startup; the "centered at startup" the
    operator saw was the servos holding their prior/limp pose during the long pre-stand
    window (countdown + gyro cal) before standPose runs.
    - isp_leg: keep lastServoAngles() (handy diagnostic: last-commanded servo degrees).
    - isp_robot_dog: remove the temporary init-stand debug print.
    - test_backend: countdown 15 -> 8 s so the init STAND (right after gyro cal) is
    easy to see.
    Co-Authored-B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
2026-06-02 Theory-of-Ops 6.1: smooth-motion engine implementation guide
    Capture the agreed smooth-motion architecture as our implementation guide, with the
    port-vs-invent split against the Freenove reference (Control.py):
    - Model: isp_leg = IK/angle provider; isp_robot_dog = conductor. One fixed-rate (~50 Hz)
    frame loop writes ALL legs+head together. Synchronized joint timing (shared s, ease-in/out)
    within a leg; shared s / gait phase across legs. Joint-space lerp for poses, Cartesian
    foot-path + per-frame IK for gaits. Blend between motions (no gaps).
    - PORT from REF Control.py: run() (write-all-legs from point[]), stop() (N-step synchronized
    lerp), the Cartesian gait trajectories + speed kno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
2026-06-02 Theory-of-Ops 6.1: add the quality bar — beat Freenove's staccato motion
    Record the north-star: Freenove's own videos look wobbly/staccato (a platform
    artifact -- single-threaded Python on a Pi sharing the CPU, no RTOS, linear steps).
    We aim to clearly beat that by exploiting P2 parallelism + determinism the Pi can't:
    dedicated motion cog, CT-timed fixed-rate loop, ~free CORDIC IK, smart pins, and
    real-time IMU balance on a parallel cog. Staccato = timing (ours to win); residual
    wobble is mechanical/dynamic (gait tuning + IMU balance).
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2026-06-03 Smooth-motion sprint §7: bench verification playbook + gait-catalog driver
    Completes the smooth-motion / 3-cog / IMU-leveling sprint (build 0.1.1).
    - NEW src/test_gaits.spin2: production-path driver that posts every gait
    (forward/backward/turn L-R/step L-R) plus the speed knob (slow/fast)
    through the backend mailbox (dog.postCommand). Mirrors test_backend's
    pattern; closes the §3 coverage gap (the scripted top only drove
    FORWARD + TURN_LEFT). End marker TEST_DONE.
    - NEW DOCs/plans/SMOOTH-MOTION-AND-INTEGRATION-TEST-PLAYBOOK.md: numbered,
    pass/fail-keyed bench playbook driving everything through the production
    mailboxes. Compile-gate first, then four headless driver flashes
    (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
2026-06-03 Rework bench harnesses to production 3-cog shape only
    Per directive: never test a non-production cog shape. The single-cog
    harnesses launched only cog1 (backend) — a shape we never ship.
    - Retire test_backend / test_level / test_gaits (single-cog).
    - Add production-shape scenario tops that ALWAYS launch both service
    cogs (cog1 backend/I2C + cog2 IO) and isolate by what cog0 commands:
    test_dog_stand -> STAND_DONE (eased poses, §1/§2)
    test_dog_level -> LEVEL_DONE (IMU static leveling, §5)
    test_dog_gaits -> GAITS_DONE (full gait catalog + speed, §3)
    The IO cog is held quiescent for these (static dim-green "alive" LED,
    ranging dormant — no IO_RANGE_ON sent, so th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
2026-06-04 Fix relax shoulder-swing + BR diagnosis; move telemetry + stack-overflow guards
    Bench bring-up of the smooth-motion engine surfaced two real defects and
    added the diagnostics that found them.
    Defects fixed:
    - relaxPose zeroed lateral Z (0,0) while stand/sit keep ±STANCE_LATERAL_MM,
    so every coxa swung toward center on RELAX (a = 90 - atan2(z,y)). Relax now
    holds the lateral stance; only X/Y (the tuck) change. No more shoulder swing.
    - Backend task stacks were 64 longs -- the CORDIC IK chain (moveToXYZ) overflows
    that; the cog froze after seedStand so it stood but ignored all commands.
    TASK_STACK_LONGS 64 -> 192; right-size later via reportStackUse.
    Diagnostics added:
    - Move teleme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
2026-06-04 Diagnostics parity across all four bench rungs
    Add dog.dumpState(label) to isp_robot_dog (it owns the telemetry), so every
    bench top emits byte-identical per-leg diagnostic blocks (moveKind/mode/tilt +
    per-leg target/current XYZ + servo angles + head + battery) with no copy-paste
    drift -- test_dog_stand now calls it too.
    Replicate the stack-overflow instrumentation to test_dog_level, test_dog_gaits,
    and isp_robot_dog_top: cog stacks moved to DAT with sentinels, prepStackForCheck
    before launch, setStackCheck after. Each rung now dumps state at meaningful
    points (level: at-measure stand; gaits: mid-gait + after STOP; top: per phase).
    Compile sweep: 40/40 clean.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
2026-06-04 Gentle power-on glide, deeper crouch, battery warnings, stance trim
    From bench bring-up of the IMU-leveling rung:
    - CMD_CROUCH: new low symmetric crouch pose (feet under body, X=0). Used as
    the consistent approach pose for repeatable leveling -- always reach STAND by
    RISING from the crouch so servo backlash is taken up in one direction. The
    3-cycle crouch-approach made the tilt measurement repeatable within ~0.3 deg.
    - Power-on now GLIDES up: seedStand snaps once to the deep crouch (low-stress),
    then eases to the level stand over ~1.5 s (POWERON_FRAMES) instead of snapping
    to attention -- lower peak current, observable rise.
    - CROUCH_HEIGHT_MM 70 -> 55 (deeper crouch).
    - Battery w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
2026-06-05 Add SHAKE and SALUTE paw-gesture commands + tricks bench driver
    New CMD_SHAKE / CMD_SALUTE one-shot gestures on isp_robot_dog: ease into a
    stable SIT base, act with the right-front paw (handshake bob / held salute),
    lower the paw, and hold the sit until a later STAND/STOP. Staged state machine
    (GST_SIT_IN -> GST_ACT -> GST_PAW_DOWN) reuses the eased pose path -- no snaps.
    test_dog_tricks.spin2 exercises SIT/SHAKE/SALUTE through mailbox A in the
    production 3-cog shape. Compile-verified only; on-hardware behavior is PENDING
    the certification sprint.
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2026-06-06 Add interactive move-panel + power-on soft-start + HELLO rebalance
    - test_dog_panel.spin2: a DEBUG-PLOT clickable control panel (production
    3-cog shape) that posts every command through the real mailboxes, with a
    live mode/battery/tilt/head/dist/ping readout. Mouse Y is bottom-left
    origin (flipped on input). Buttons: momentary moves, latched gaits,
    toggle LED/RANGE, radio speed. Logs settled IMU tilt after STAND/CROUCH/
    RELAX. Asset generator: tools/gen_dog_panel_assets.py (+ 4 BMPs).
    - isp_robot_dog.spin2 power-on soft-start: slam once to a safe low neutral
    stance, then ease into RELAX (dog powers up resting, not standing).
    - HELLO now rebalances first: leanStandFoot() shifts th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
2026-06-06 docs: futures detail page + concise README summary
    - DOCs/FUTURE-DIRECTIONS.md: per-direction detail (speech / pan-tilt+vision
    camera / P2 audio / BLE) with hardware candidates, interfaces, and P2
    integration notes.
    - README "Possible future directions" trimmed to a summary linking the new
    page; speech promoted to short-term, P2 audio added, stale "where does
    inference run" caveat dropped (I2C camera answers it).
    - .gitignore: keep DOCs/REF-NO-COMMMIT/ out of the repo by intent.
2026-06-07 Correct servo range to 500-2500us + re-calibrate
    The servo driver mapped 0-180 deg to 800-2200us, which is only ~126 deg of
    the servos' real travel (reference Servo.py uses 500-2500us = counts 102/512
    @ 50Hz). Widen DEFAULT_LIMIT_USEC to 500/1500/2500 so the engine drives the
    full 0..180 deg (1 commanded deg == 1 real deg). Full re-meter of legTrim +
    head trim under the corrected mapping (supersedes 2026-06-03).
    Note: stance-leveling trim is now stale -- re-measure on the bench.
2026-06-07 Trick commands, gait-transition fixes, dialed salute
    - New CMD_*: LIE_DOWN (sphinx), BOW (play-bow), PUSHUPS, NOD (head tilt),
    PARADE_REST (tall low-torque stand), SET_SPEED (live gait-speed change).
    - Gaits: eased stop-to-neutral LEAD-IN before every trajectory (no snap
    between gaits / from a pose); SET_SPEED applies live to a running gait.
    - Push-ups now lead-in to stand before bobbing (no snap); nod slowed to 2/3.
    - HEAD pan now applies cal.headTrim() (CMD_HEAD was sending raw angle).
    - SALUTE drives the FR paw to hand-dialed RAW servo angles (166/139/80) via
    new isp_leg.driveServoDegrees(); levels the head; HELLO-style rebalance
    retained. seedStand soft-start to RELAX retained.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
2026-06-07 Bench tools: panel 5th row + DEBUG_MASK; Cal range + load-calibration
    - Move panel: 5th button row (DOWN/BOW/PUSHUP/NOD/SPIN/SPEAK), r-key parade
    rest, LED button steps through patterns, speed buttons post SET_SPEED
    (live), DEBUG_MASK channels (mouse/input noise off by default).
    - Cal tool: span 500-2500us, trim +/-95, and a 'k' key to load the committed
    calibration (start centered; C still zeros) so poses dial from true neutral.
2026-06-07 Per-joint servo clamps from measured limits + Cal trim logging
    Measured the real drivable range of each leg joint on the bench (servos are
    unmarked MG90S-class metal-gear; no datasheet, so our bench numbers are the
    spec). Servos drive ~10-170 deg (~+/-80 from center); past that they stop with
    no noise (pulse edge, not a mechanical stop). Per-joint mechanical cuts: coxa
    inward hits the body (65 deg), tibia inward hits the housing (~15 deg).
    isp_leg now clamps each joint to its drivable range (coxa 65-170, femur 10-170,
    tibia 20-170) in both setJointAngles and driveServoDegrees, replacing the blanket
    0-180. Cal (test_cal_full) logs trim->us per move for range/limit capture.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
2026-06-07 docs: per-folder README index across DOCs; rework Freenove page to our licensing
    - Add house-style README.md to every DOCs subfolder that holds md/pdf and
    lacked one: datasheet, dbg-display-theory, plans, plans/archive, policy,
    reference, spec — each describes its contents and links to them.
    - Rework DOCs/README.md: was a verbatim Freenove kit README (CC BY-NC-SA);
    now our MIT-licensed DOCs hub that indexes the tree and *attributes* the
    Freenove FNK0050 reference material (REF/ + kit photos) without claiming it.
    - Picture/README.md: retarget the "Freenove kit README" link to the DOCs hub.
    - Land DOG-LIKE-MOTION-STUDY.md (canine-biomechanics findings, sources verified).
    Co-Authored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
2026-06-07 docs(study): commit the interleaved 10-step implementation order (§6)
    Replace the provisional 'suggested order' with the agreed, committed sequence
    that interleaves mechanics-depth steps with visible/fun bench payoffs, so
    improvements are seen along the way rather than all visuals landing last.
    Keystone first; coxa activation precedes trunk roll + coxa-showcase behaviors;
    tail+head-pan land later (hardware-gated).
2026-06-07 docs(plans): retool cert to control-panel sweep; sequence pre-keystone work
    - Cert plan: recast from a manual exercise-by-exercise playbook into a
    control-panel functional sweep (test_dog_panel.spin2), repositioned as the
    Dog-Like Motion arc entry baseline + non-singleton I2C-cutover regression
    gate. Three-tier verify model (compile / panel sweep / scripted end-marker
    drivers), calibration de-scoped to durable servo-trim + sign-lock (stance
    pitch/roll residual deferred to keystone), new §6 re-cert, §0 decisions
    refreshed with recommendations.
    - Keystone plan: add Entry-prerequisites (cert + I2C cutover land first) and a
    fixed-spine constraint section + §1 coupling note (rigi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
2026-06-07 docs(playbook): record 2026-06-07 panel pass — Ex0-8 results + F1-F4 findings
    Annotate the smooth-motion/integration playbook as the living bench record of the
    control-panel functional pass (logs debug_260607-165851 + -170945):
    - Checked off: Ex0 compile, Ex2 eased poses, Ex4 gaits+live speed, Ex6
    concurrency/blend + ranging-live-during-gait (visual), CMD_CROUCH/STAND,
    PARADE-REST. Ex3 leveling deferred to keystone; Ex5 FAIL (paw-gesture tip);
    Ex7/8 n/a (healthy pack).
    - Aggregated findings F1 (BOW head-to-table), F2 (panel LED-mode readout),
    F3 (LED SOLID/WIPE/CHASE render black), F4 (SHAKE/SALUTE no rebalance -> tip)
    into a "fix, then retest" table; D1 (gait-transition smoothin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
2026-06-08 BENCH-REPAIRS-01 Part B: implement F5–F8 (compile-green 42/42)
    - F5 BOW head-return: savedHeadDeg/headReturnPending; the bow snapshots the
    pre-bow head, the pose leaving the bow eases it back, CMD_HEAD cancels.
    - F6 gesture re-level: new GST_LEVEL_OUT eases the leaned sit -> a level,
    centered sit after the paw lowers (SHAKE/SALUTE end balanced; HELLO unchanged).
    - F7 HELLO foot-depth: HELLO_LIFT_MM=40 retracts the wave off the floor, the
    lift eased in over the lead-in (no snap).
    - F8 battery <5V hard-floor: CRITICAL_BATTERY_MV=5000 + isCriticalLowConfirmed()
    3-read confirm-burst (rejects a recovering sag); applySafetyFloor eases to
    RELAX + latches a motion-refusing HALT; consumeC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
2026-06-08 BENCH-REPAIRS-01 closeout: F5–F8 bench-verified, IMU instrumentation fix, ship 0.1.2
    Close the Bench-Repairs-01 sprint with all F1–F8 bench-verified on the P2
    bench unit (2026-06-08). Compile sweep 42/42 green.
    Retest instrumentation (the charged-pack retest exposed two measurement
    bugs; firmware motion behavior was always correct):
    - test_dog_panel: SETTLE_POLLS=48 (~1.2 s) dwell + movePhase 2 in watchMove
    so getAttitude() is sampled after the body settles, not mid-transition.
    - isp_imu.tiltDegrees(): the MPU6050 is mounted rotated 90° in yaw, so pitch
    is now computed from accel Y (fore/aft) and roll from accel X (lateral).
    Fore/aft mapping bench-confirmed; lateral (roll) sign s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
2026-06-09 DOG-LIKE-MOTION-01 plan-to-tasks: add section↔task cross-reference table
    7 todo-mcp tasks created (#13–#19, tag dlm01-keystone), seq 1–7 foundational→
    dependent. Rework-analysis swap: §6 code audit (seq 5) before §5 doc backport
    (seq 6) so an audit-driven rename can't force doc rework.
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2026-06-09 Sprint closeout: DOG-LIKE-MOTION-01 Keystone (build 0.2.0)
    Closes + archives the keystone sprint. The loaded-rear-crouch neutral
    (neutralFootTarget) shipped in §1-§6 is bench-verified (§7): the dog stands
    level, and all poses/gaits/gestures certify with end-markers.
    §7 bench findings, fixed in-sprint:
    - SALUTE re-architected to a STANDING gesture (advanceSalute reuses HELLO's
    leaned-stand rebalance; CMD_HELLO/CMD_SALUTE share GST_LEAN_IN; SHAKE stays
    seated; advancePawGesture is SHAKE-only). Bench-verified no tip.
    - LIE_DOWN reworked to a low flat rest (LIEDOWN_FRONT_X_MM=0, HEIGHT=50,
    LATERAL=6) -- a forward reach rotated the paw up off the floor in this leg
    geometry. New PUB l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
2026-06-10 LIE_DOWN: keep low flat rest (Y=50), make host-gate lie-down check advisory
    Stephen verified the reworked lie-down on the bench: level (pitch -2 / roll -1),
    paws flat ("down looks much better now"). At Y=50 the right-front leg rides at
    its fully-folded DRIVABLE limit (FR femur/tibia at clamp), which the strict gate
    flagged as FAIL.
    Decision (Stephen): keep the better-looking low/level pose; soften the gate.
    test_keystone_geometry's lie-down check is now ADVISORY -- a joint at its
    drivable limit logs a WARN, not a FAIL (it's an intended fold-limit within the
    measured range, not a hard stop). The NEUTRAL stance check stays strict.
    A genuinely lower (belly-down) lie-down needs the FL-coxa (~-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
2026-06-10 Retire the serial-term subsystem; gut hidden UTF-16 pca9685 driver
    Removes the now-unused serial-terminal stack entirely:
    - isp_dog_bringup.spin2 -- the standalone menu console; the only
    live term user, superseded by the test_* harnesses + DEBUG()'s
    PC_KEY/PC_MOUSE. It was also the only isp_-prefixed TOP (PUB main),
    violating the "isp_ = objects" convention.
    - isp_serial_singleton.spin2 -- debug UART; nothing references it now.
    - jm_nstr.spin2 -- number formatting; only the serial
    object used it (pca9685_servo's lone itoa went with interpModeValue).
    Also guts term from isp_i2c_pca9685.spin2 -- a 15th term user that the
    survey missed because the file wa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
2026-06-10 VOICE-INT §1: point voice driver at isp_i2c (clock-stretch bus 2)
    DF2301Q clock-stretches; isp_i2c_singleton had clock-stretch removed
    and is bus-1-scoped. Swap the driver's OBJ to the VAR/instance isp_i2c
    master (honors STRETCH_LIMIT) so its single instance becomes bus 2.
    API-parity verified; only DAT->VAR scope + restored stretch differ.
    Compile sweep green 44/44 (incl custom_words_example, the other
    instantiator). «#20»
2026-06-10 VOICE-INT §2: IO cog owns bus 2, publishes recognized-CMDID telemetry
    isp_io_controller adds the DF2301Q voice recognizer as a 4th
    cooperative round-robin task on a 2nd I2C bus it owns. It only
    PUBLISHES telemetry (voiceCmdId/voiceCmdSeq + getVoiceCmdId/getVoiceSeq,
    mirroring distMm/pingSeq) — no mapping, no posting.
    - startWithVoice(led,buzz,trig,echo,vScl,vSda); start() delegates with
    VOICE_OFF sentinel so the 5 quiescent test tops stay untouched.
    - stepVoice() 0->nonzero edge-detects pollCMDID(): the driver caches the
    CMDID for ~50ms and the loop has no delay, so a bare nonzero would
    bump seq thousands of times per recognition. The device clears its
    reg on read, so repeated id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
2026-06-10 VOICE-INT §2: drop redundant bVoicePresent re-init (simplify pass)
    bVoicePresent defaults FALSE from its DAT initializer, exactly as the
    sibling booleans (ledActive/buzzing/rangingOn) do — the explicit
    re-init in startWithVoice was the inconsistent outlier. Removing it
    matches the file's established idiom. No behavior change.
    Compile sweep green. «#21»
2026-06-10 VOICE-INT §5: minimal green-LED blink on voice recognition
    stepVoice fires a brief (120ms) green ring blink on each fresh
    recognition edge, then self-expires back to off — non-blocking
    (mirrors the buzzer timed-off pattern) and re-armed per recognition
    so rapid words never leave the ring stuck on. Clears ledActive/ledBusy
    so stepLed won't animate over it. Voice-disabled builds never blink
    (gated by bVoicePresent). Green only this sprint; the full
    red/spinning-green scheme is documented for the mapping sprint (§6).
    Compile sweep green 44/44. «#22»
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2026-06-10 VOICE-INT §7: bench verification playbook + record the automated compile gate
    Authored DOCs/plans/VOICE-INTEGRATION-TEST-PLAYBOOK.md (build 0.3.0, Stephen-
    driven) -- the on-hardware proof for the voice wiring-in. Six exercises:
    0 automated compile-sweep gate (45/45, host) -- run first, gates the rest
    1 bus-2 electrical pre-flight [ELEC] -- meter SDA/SCL idle + supply rail,
    RESOLVES the open §3a item that sets VOICE_I2C_PULLUP (PU_NONE vs PU_1K5)
    2 bus-2 recognition via test_voice (dog unpowered/safe) -- the headline
    "do we hear commands, which CMDIDs" gate: present=T, correct CMDID+phrase,
    unknown prints nothing, verbal ACK + green blink
    3 bus coexistence -- full robot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
